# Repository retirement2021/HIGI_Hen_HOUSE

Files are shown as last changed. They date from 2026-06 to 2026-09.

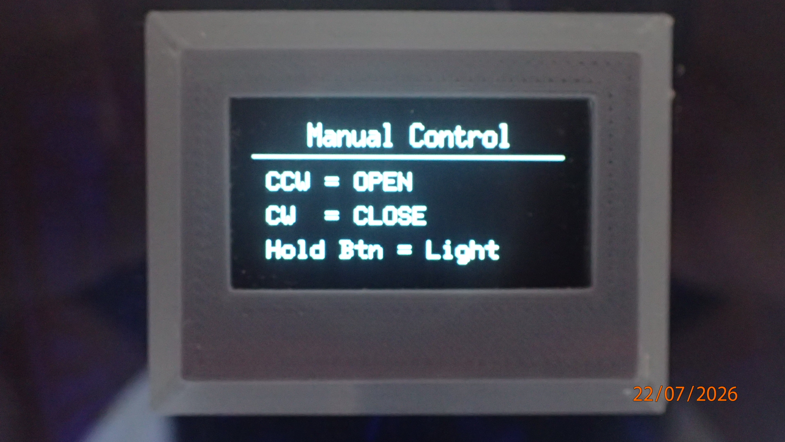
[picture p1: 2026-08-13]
Photos/Manual Page.png

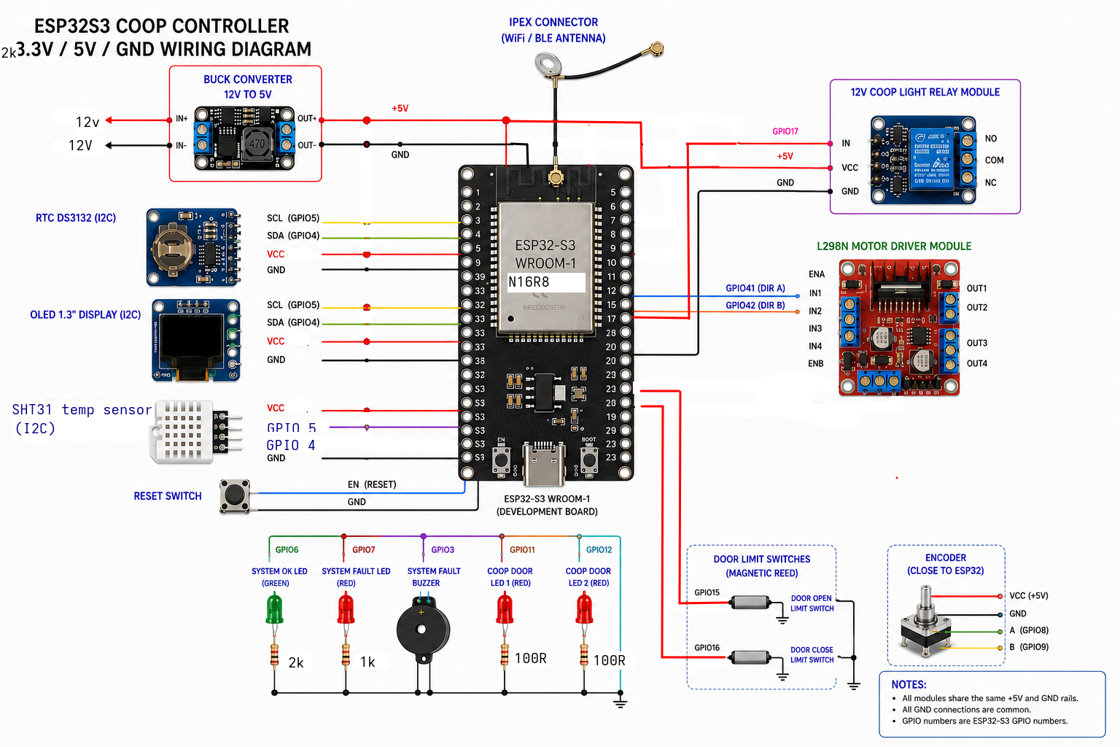
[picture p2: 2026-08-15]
Wiring/Logic Level Wiring Diagram.png

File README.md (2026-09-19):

# 🐔 Automated Hen House Controller

### ESP32-S3 based automatic chicken-coop door, lighting and environmental monitoring system

An automated hen-house control system built around an **ESP32-S3**. The system controls a **guillotine-style chicken door powered by a geared motor**, providing automatic opening and closing while incorporating multiple safety features to protect the hens and the mechanism.

The controller also provides environmental monitoring, automatic lighting, an OLED user interface, event logging, Wi-Fi time synchronisation and long-term temperature/humidity recording.

---

## ✨ Features

* 🐔 **Automatic guillotine-style door**
* ⚙️ Geared motor drive with OPEN/CLOSE control
* 🌅 Sunrise/sunset based scheduling
* 🕐 Separate GMT and BST schedules
* 🌡️ Inside and outside temperature/humidity monitoring
* ❄️ Cold-weather morning opening delay
* 💡 Automatic evening coop lighting
* 🔴 Progressive night/bedtime warning LEDs
* 🛡️ Door obstruction detection and recovery
* 🚪 Limit-switch monitoring and motor timeout protection
* 🔒 Fault detection and lockout system
* 🔔 Audible fault alarm
* 📊 14-day environmental history
* 📝 100-entry event log
* 🕰️ DS3231 RTC with NTP time synchronisation
* 📶 Wi-Fi monitoring and automatic reconnection
* 🖥️ 128×64 SH1106 1.3" OLED display
* 🎛️ Rotary encoder user interface
* 💾 Persistent settings and data storage
* 🐕 Watchdog protection for unattended operation

---

# 🏠 Door System

The hen house uses a **vertical guillotine-style door** driven by a **geared motor**.

The motor is controlled in both directions to raise and lower the door, with dedicated limit switches confirming the fully open and fully closed positions.

The door controller uses a state-machine architecture rather than simply running the motor for a predetermined time.

### Door safety features

* Separate OPEN and CLOSED limit switches
* Motor direction interlock
* 50 ms direction-change safety delay
* motor timeout
* Door position detection at startup
* Automatic homing if the door position is unknown
* Limit-switch conflict detection
* Closing obstruction detection
* Automatic reopening after an obstruction
* Times chicken-release period
* Maximum obstruction retries
* Fault and lockout states
* Manual fault reset

If the door encounters an obstruction while closing,  the door automatically reopens to allow the Chicken to clear the area before attempting to close again.

---

# 🌅 Automatic Door Operation

Door operation can be configured around **sunrise and sunset**, or fixed open times.

Separate settings are available for:

* **GMT / winter**
* **BST / summer**

The controller automatically detects UK daylight-saving time and selects the appropriate schedule.

The fixed opening times can be disabled to allow the door to operate relative to sunrise instead.

---

# ❄️ Cold Weather Protection

An external waterproof **SHT30 temperature/humidity sensor** monitors the outside temperature.

If the outside temperature is below the configured threshold when the morning door opening is due, the system can delay opening.

If the temperature rises above the threshold during the delay, the door can open immediately.

A manual override is also available to allow the door to open regardless of the outside temperature.

A dedicated blue LED indicates when the outside temperature is below the configured cold threshold.

---

# 🌡️ Environmental Monitoring

Two Sensirion SHT3x-family sensors are used.

| Sensor | Location | I²C Address |
| --- | --- | ---: |
| SHT31  | Inside hen house | `0x45` |
| SHT30  | Outside | `0x44` |

The sensors monitor:

* Temperature
* Relative humidity
* Daily minimum temperature
* Daily maximum temperature
* Daily minimum humidity
* Daily maximum humidity
* Time of recorded extremes

Approximately **14 days of environmental history** is retained for both inside and outside measurements.

Data is stored using the ESP32 `Preferences` system so that it survives power loss.

---

# 💡 Lighting & Night System

The controller operates the hen-house light automatically around sunset.

The evening chicken homing system uses two LEDs to provide a visual indication as closing time approaches.

The homing sequence progressively increases the flashing rate as the door-closing time gets closer.

Once the door is confirmed fully closed, the LEDs enter **night mode** and alternate throughout the night.

The coop light can also be operated manually using the rotary encoder.

---

# 🖥️ User Interface

A **128×64 SH1106 OLED** provides information and limited control without requiring a computer or web interface.

The rotary encoder is used for navigation and manual control.

### Display pages

1. **Main Status**
2. **Today's Schedule**
3. **Inside Environment**
4. **Outside Environment**
5. **Manual Controls**
6. **Event History**
7. **Wi-Fi Status**
8. **System Time**

The display normally refreshes only when required to reduce unnecessary I²C activity. 

The OLED also enters power-save mode after a period of inactivity.

---

# 📝 Event Logging

The controller maintains a circular **100-entry event history** with time stamps.

Events include:

* Automatic door opening
* Automatic door closing
* Manual door operation
* Light operation
* Cold-weather delays
* Obstruction detection
* Door timeouts
* Homing operations
* Faults
* Wi-Fi events
* Sensor faults
* System resets

This provides a useful history when diagnosing the system or checking its operation.

---

# 🕰️ Timekeeping

The system uses two time sources:

### Primary

**NTP via Wi-Fi**

### Backup

**DS3231 RTC**

When Wi-Fi is available, the ESP32 synchronises its clock using NTP and updates the DS3231.

If Wi-Fi is unavailable, the RTC provides a backup time source so that automatic door operation can continue.

UK GMT/BST daylight-saving rules are handled automatically.

---

# 📶 Wi-Fi

Wi-Fi is primarily used for:

* NTP time synchronisation
* Connection monitoring
* Automatic reconnection
* Signal-strength monitoring
* IP-address display

The controller is designed so that normal hen-house automation does not depend on a permanent Wi-Fi connection.

---

# 🔌 Hardware

### Controller

**ESP32-S3 WROOM-1 / N16R8**

### Display

**1.3" 128×64 SH1106 OLED**

### Sensors

* Sensirion SHT31 – inside
* Sensirion SHT30 – outside (waterproof)

### RTC

**DS3231**

### Door

* Guillotine-style vertical door
* Geared DC motor
* Motor driver
* OPEN limit switch (reed switch)
* CLOSED limit switch (reed switch)

### User control

* KY-040 rotary encoder

---

# 📌 ESP32-S3 Pinout

| Function | GPIO |
| --- | -----: |
| I²C SDA |  **8** |
| I²C SCL |  **9** |
| Rotary Encoder CLK |  **4** |
| Rotary Encoder DT |  **5** |
| Encoder Button | **18** |
| Door Motor OPEN | **41** |
| Door Motor CLOSE | **42** |
| Door OPEN Limit | **15** |
| Door CLOSED Limit | **16** |
| Coop Light | **17** |
| Green Status LED |  **6** |
| Red Fault LED |  **7** |
| Night LED 1 | **11** |
| Night LED 2 | **12** |
| Cold Temperature LED | **13** |

All I²C devices share the same bus at **100 kHz**.

---

# 🛡️ Safety Philosophy

Because the system controls a physical door containing live animals, safety is a major part of the design.

The controller does not rely on a single timing mechanism to determine door position.

Instead it combines:

**Limit switches + motor timeout + state machine + obstruction detection + recovery + fault lockout**

The system also performs a door-position check during startup and will attempt to home the door if its position cannot be established.

---

# 💾 Firmware

**Current Version: V2.14**

The project has evolved through several revisions, including the transition from a DHT22 sensor to the SHT3x family and the addition of the external temperature sensor and cold-weather door protection. Additional refinements and tweaks to get as close to a plug and play install as i can.

### V2.04 highlights

* SHT31 inside sensor
* SHT30 outside sensor
* Dual I²C sensor support
* Outside environmental monitoring
* Cold-weather opening delay
* Temperature-based delay cancellation
* Persistent environmental history
* Improved event logging
* Environmental log maintenance functions

---

# 🔧 Development Notes

The OLED, DS3231 and both temperature sensors share the same I²C bus.

Reliable physical wiring is important for I²C operation. In testing, intermittent display problems were ultimately traced to unreliable **fly-lead connections between the ESP32-S3 and OLED**. Replacing the leads and soldering the connections resolved the problem.

This is worth considering when reproducing the hardware, particularly where longer or flexible wiring is used.

---

# ⚠️ Disclaimer

This is a personal DIY automation project.

A motorised animal door should be thoroughly tested under real operating conditions before being left unattended. Particular attention should be given to the mechanical door design, limit switches, obstruction detection, motor drive system and emergency/fault conditions.

---

## 📷 Project

**Hen House Automation — ESP32-S3**

*Automatic door • Environmental monitoring • Lighting • Safety • Data logging*

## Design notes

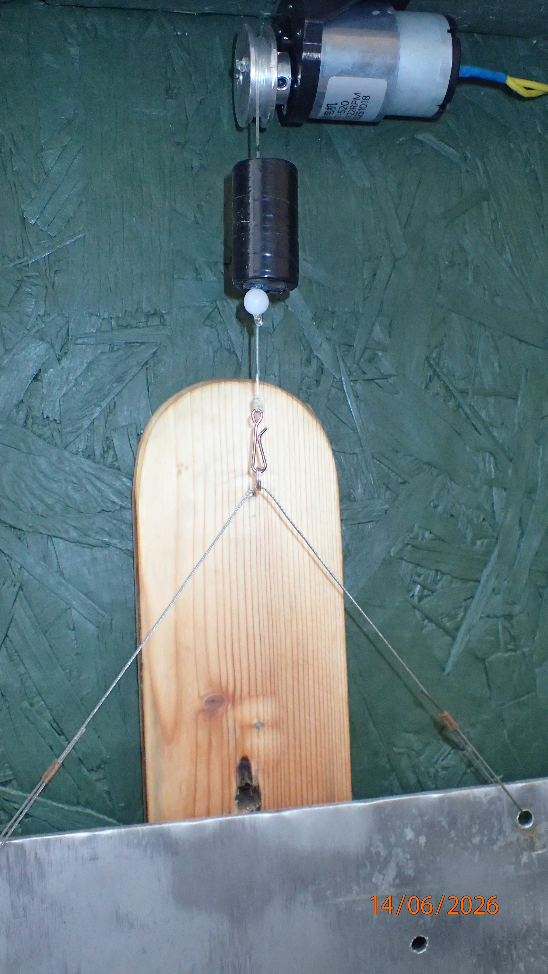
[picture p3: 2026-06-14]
Photos/150g weight to take up slack.JPG

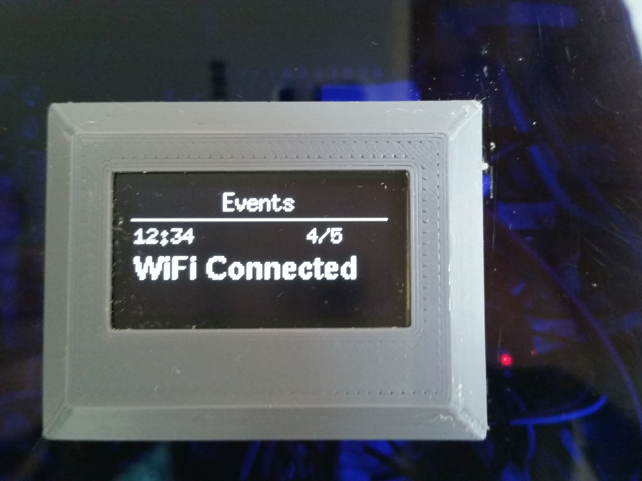
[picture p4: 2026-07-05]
Photos/Events page.jpg

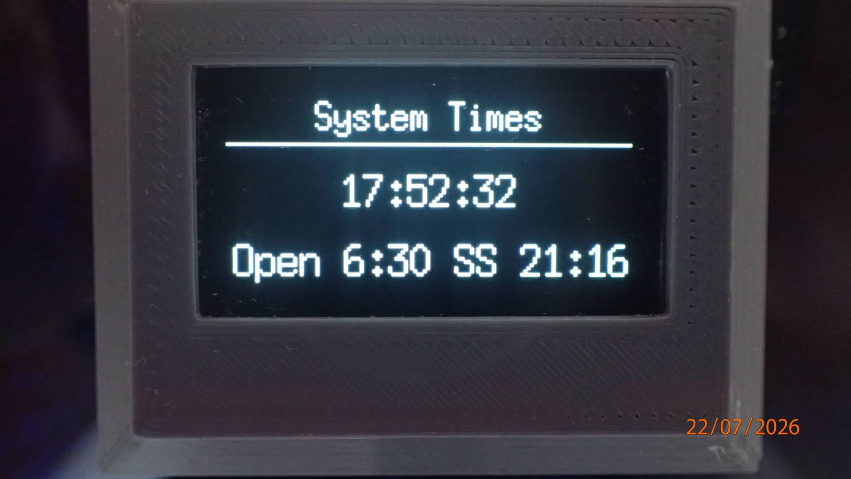
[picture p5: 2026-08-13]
Photos/System Times.png

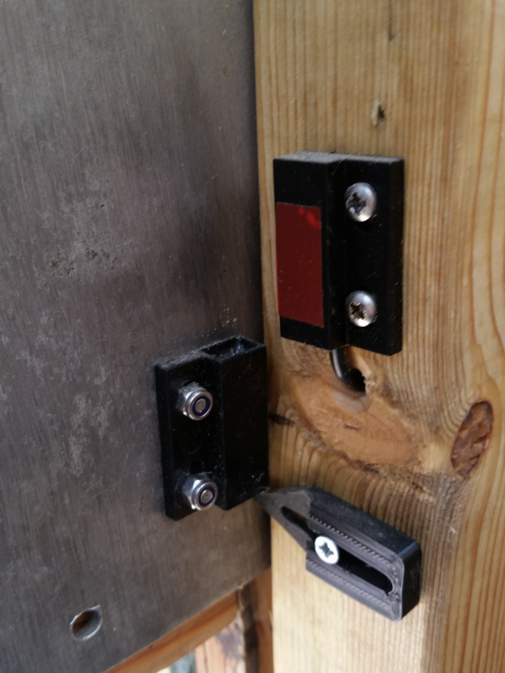
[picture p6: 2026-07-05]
Photos/Upper-limit switch.jpg

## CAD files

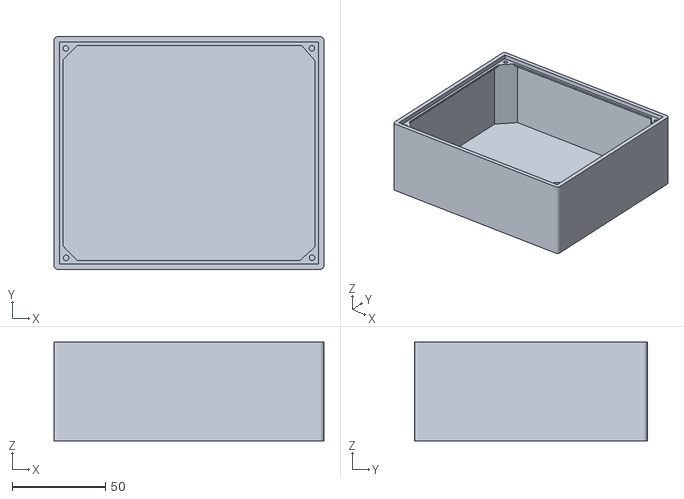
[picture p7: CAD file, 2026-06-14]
3D Printed parts/Control box/Hen House Control Box.stl
145.0 x 125.0 x 53.0

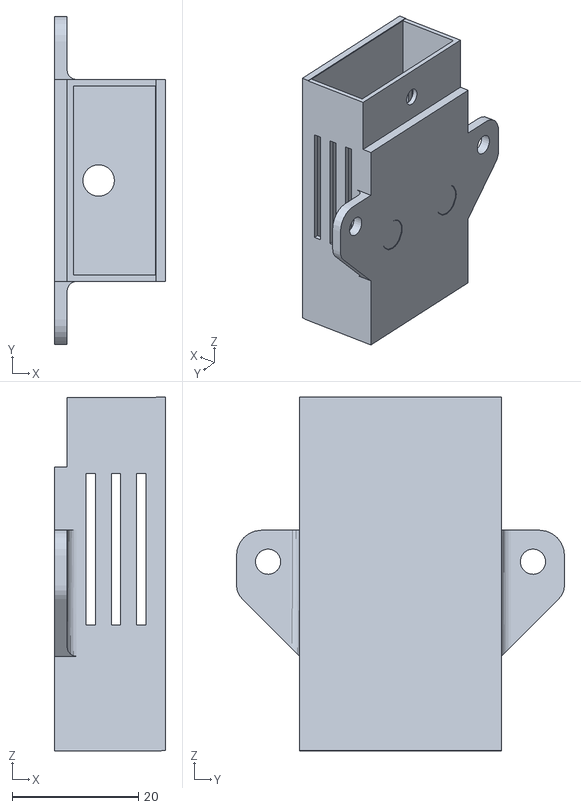
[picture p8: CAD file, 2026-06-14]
3D Printed parts/DHT temp sensor box/DHT box .stl
17.6 x 52.0 x 56.1

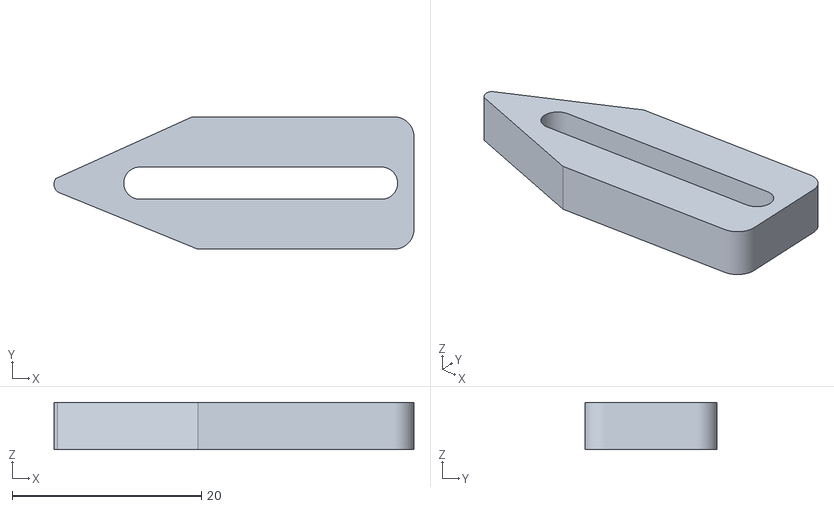
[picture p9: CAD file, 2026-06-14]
3D Printed parts/Door slider fine adjust/door slider points, 2 per side.stl
38.1 x 14.0 x 5.00

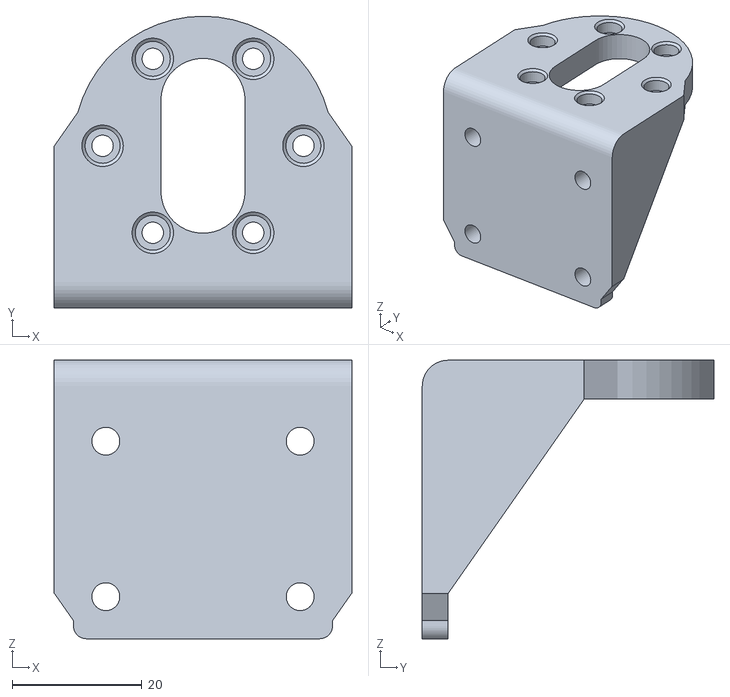
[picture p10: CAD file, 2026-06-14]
3D Printed parts/JGB37-520 Motor Mount.stl
46.0 x 45.0 x 43.0

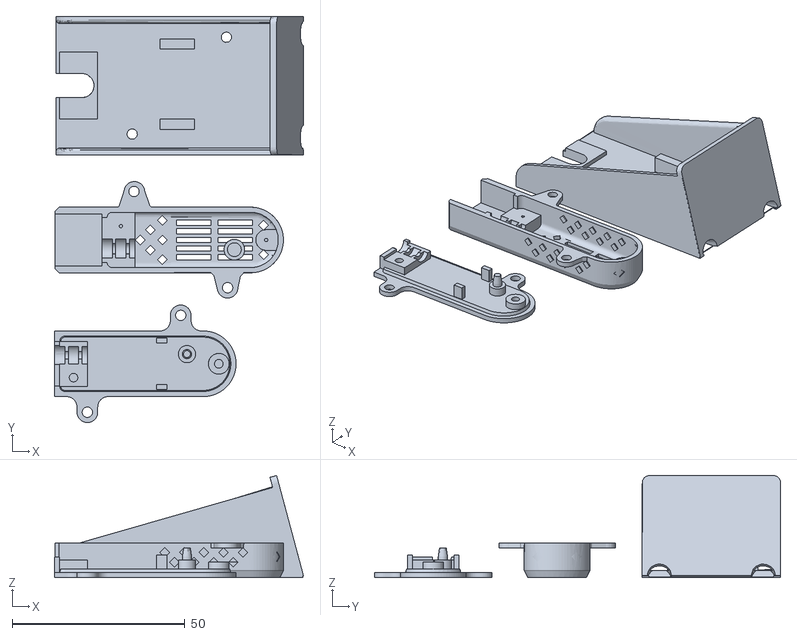
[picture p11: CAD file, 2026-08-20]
3D Printed parts/SHT Temperature sensor Enclosures/SHT Coop Sensor Mount.stl
72.0 x 117.4 x 29.5

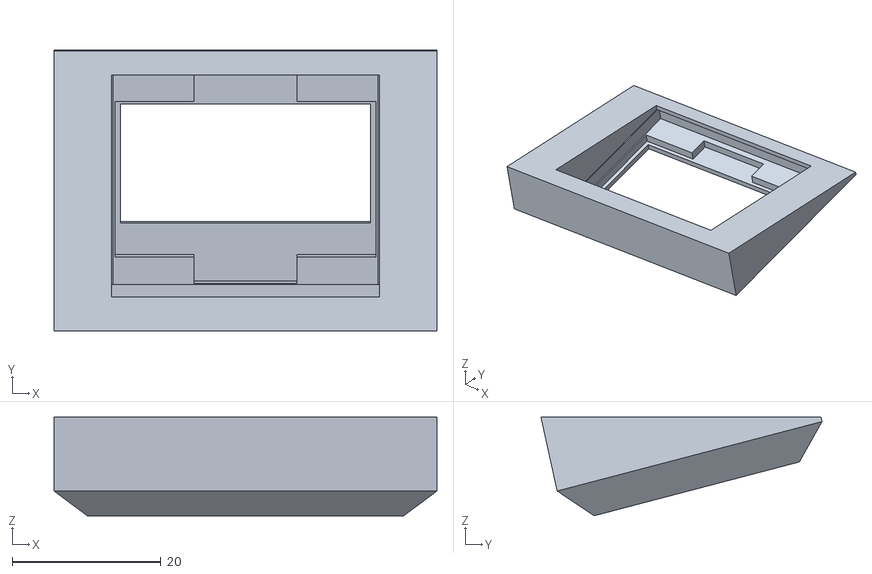
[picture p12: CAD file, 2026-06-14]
3D Printed parts/Control box/1.3 angled Bezel MKII.stl
51.5 x 37.8 x 13.2

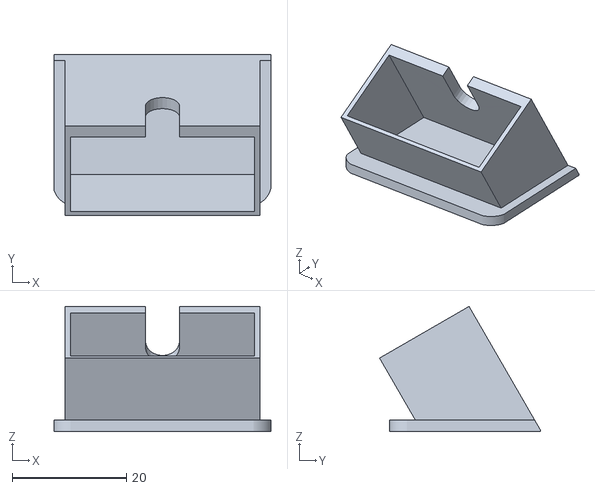
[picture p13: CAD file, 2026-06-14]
3D Printed parts/DHT temp sensor box/DHT lid .stl
38.0 x 28.2 x 21.9

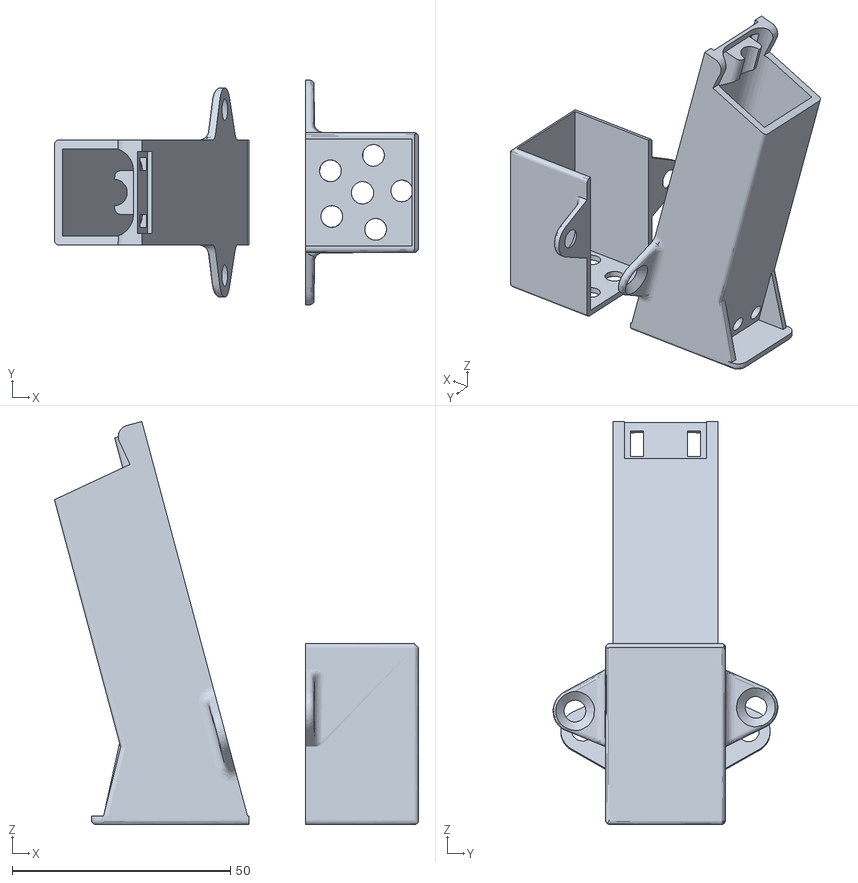
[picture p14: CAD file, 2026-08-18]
3D Printed parts/SHT Temperature sensor Enclosures/ SHT Outide Sensor Enclosure .stl
83.5 x 51.5 x 92.3

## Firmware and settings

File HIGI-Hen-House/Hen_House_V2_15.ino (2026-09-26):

// System: ESP32S3 N16R8 board.
// Arduino IDE: ESP32S3 Dev Module

// Author HIGI-Styx
// Febuary-September 2026


//  https://github.com/retirement2021/HIGI_Hen_HOUSE for Robust versions, wiring diagrams, photos, 3D printing files, and a complete parts list.

// 2.15
// Long term 

// V2.14
// NVS logging problems reducing the amount of data and the number of days that can be comfortably stored

// V2.13
// Remove the current time and 1 second refresh on System Time page and replace with Cold threshhold temp.
// Change the title of that page to Cold & Daytime.

// V2.12
// Amalgamated inside and outside environmental pages into one, for convenient viewing.

// V2.10
// removed the clear persistent environment logs on the next upload as it was the culprit to NVS logging fails.

// 2.04
// Rewrote the Environment Outside pages inline with the Environment Inside pages for consistency.
// Futher refinement to the cold delay logic to poll the external temperature sensor immediately before the door opens, then reset the polling timer.

// V2.02
// Refined cold delay logic to evaluate temperature immediately prior to door opening, logging a "Cold Delay" event when triggered.
// Added a option to clear internal and external persistent environment logs on the next upload.

// V2.01
// Added support for an SHT30 outdoor temperature probe at address 0x44, complete with dedicated display pages and logging.
// Replaced the Adafruit_SHT31 library with SensirionI2CSHT3x to support dual SHT3x sensors on separate I2C addresses.
// Updated the I2C address for the SHT31 coop sensor to 0x45.
// Implemented a cold weather morning door delay when outdoor temperatures fall below a configurable threshold.
// Added a 24/7 Cold (blue) LED indicator that illuminates when ambient temperature drops below the configured setpoint.

// V2.0
// Changed from a DHT22 coop temp sensor to a SHT31 sensor.


//------------------------

// This project has evolved to enable long-term autonomous operation with minimal user intervention.

// An automated coop management system that synchronizes door operation and lighting with natural sunrise/sunset times,
// Continuously tracks environmental metrics, and integrates robust safety protocols to protect the flock and hardware.

// Tailored for UK time zones and DST shifts.
// Only requires a minimal Wi-Fi signal to perform NTP time synchronization.
// All customizable settings are centralized in one block under two headers: *USER SETTINGS* and *USER MAGIC NUMBERS*.
// Integrated motor timeout protection to prevent motor burnout during mechanical door failures.
// Obstruction Protection: Smart door-reversal logic to release a trapped chicken during closure.
// Coop door and light operations sync with local sunrise/sunset times and feature fully customizable settings to accommodate your flock's routine.
// Rooster Crow Control: Optional fixed-time door opening schedule to delay early morning crowing.
// System operation uses a rotary encoder. Perform a long press (≥5 seconds) to reset system faults.



//======================================================
// LIBRARYS
//======================================================
#include <WiFi.h>
#include <time.h>
#include <math.h>
#include <Wire.h>
#include <RTClib.h>
#include "secrets.h"
#include <U8g2lib.h>
#include <Preferences.h>
#include <esp_task_wdt.h>
#include <SensirionI2cSht3x.h>
#include <AiEsp32RotaryEncoder.h>

// ======================================================
// TIME VALUES
// ======================================================
// Converts milliseconds into readable; seconds, minutes and hours.

const unsigned long SECOND = 1000UL;
const unsigned long MINUTE = 60000UL;
const unsigned long HOUR = 3600000UL;

// ******************************************************
// ********USER SETTINGS*********
// ******************************************************

//--------------------------------------
//  SYSTEM
//--------------------------------------
// Displayed firmware version
const char systemVersion[] = "V2.15";

//"""""""""""
// WINTER
//"""""""""""

//~~~~~~~~~~~~~~~~~~~~~~~~~~~~~~~~~~~~~~
// DOOR OPENING OPTION (GMT only)
//~~~~~~~~~~~~~~~~~~~~~~~~~~~~~~~~~~~~~~

// GMT (Winter only):
//   Choose sunrise OR fixed opening time
// * false = Sunrise     (GMT Winter only)
//   true  = Fixed time  (GMT Winter only) ~Rooster Crow Control
bool useFixedOpenTimeGMT = true;

// Fixed opening time for GMT Winter (24-hour clock)
int fixedDoorOpenHourGMT = 8;     // GMT fixed open hour (24-hour)
int fixedDoorOpenMinuteGMT = 00;  // GMT fixed open minute

//-------------------------------------
//  DOOR GMT TIME. (winter)
//-------------------------------------
// Positive offset = AFTER  sunrise/sunset
// Negative offset = BEFORE sunrise/sunset.

//MORNING.
// * Active only when "DOOR OPENING OPTION" is set to "false". (GMT Winter only)
// Door opening offset from sunrise - GMT
int sunriseOpenOffsetGMT = +20;  // __ minutes after sunrise

//EVENING
// Door closing offset from sunset - GMT
int sunsetCloseOffsetGMT = +15;  // __ minutes after sunset

//--------------------------------------
//  LIGHT GMT TIME. (winter)
//--------------------------------------
// Positive offset = AFTER  sunrise/sunset
// Negative offset = BEFORE sunrise/sunset.

//LIGHT ON
// Coop light ON offset from sunset - GMT
int lightOnOffsetGMT = -13;  // __ minutes before sunset

//LIGHT OFF
// Coop light OFF offset from sunset - GMT
int lightOffMinutesGMT = +7;  // __ minutes after sunset

//-------------------------------------------------------
//  OUTSIDE SHT30 TEMPERATURE SENSOR + COLD-OPEN SETTINGS
//-------------------------------------------------------

bool enableOutsideSHT = true;  // Set to "false" if no outdoor temperature sensor is installed.

float outsideTempTriggerC = -2;        // Delays scheduled door opening when outside temp is under ___ °C (also triggers 24/7 Cold LED).
int doorOpenDelayIfColdMinutes = +35;  // Minutes to delay door opening time.

bool forceOpenDespiteCold = false;  // set true to ignore door cold-delay (persistent)


//""""""""""""
// SUMMER
//""""""""""""

//~~~~~~~~~~~~~~~~~~~~~~~~~~~~~~~~~~~~~~
// DOOR OPENING OPTION (BST only)
//~~~~~~~~~~~~~~~~~~~~~~~~~~~~~~~~~~~~~~

// BST (summer only):
//   Choose sunrise OR fixed opening time
// * false = Sunrise     (BST summer only)
//   true  = Fixed time  (BST summer only) ~Rooster Crow Control
bool useFixedOpenTime = true;

// Fixed opening time for BST summer (24-hour clock)
int fixedDoorOpenHour = 7;
int fixedDoorOpenMinute = 55;

//------------------------------------
//  DOOR BST TIME (summer)
//------------------------------------
// Positive offset = AFTER  sunrise/sunset
// Negative offset = BEFORE sunrise/sunset.

//  MORNING -
//  * Active only when "DOOR OPENING OPTION" is set to "false". (BST summer only)
//  Door opening offset from sunrise - BST
int sunriseOpenOffsetBST = +30;

//EVENING
// Door closing offset from sunset - BST
int sunsetCloseOffsetBST = +20;

//------------------------------------
//  LIGHT BST TIME (Summer)
//------------------------------------
// Positive offset = AFTER  sunrise/sunset
// Negative offset = BEFORE sunrise/sunset.

//LIGHT ON
// Coop light ON offset from sunset - BST
int lightOnOffsetBST = -7;

//LIGHT OFF
// Coop light OFF offset from sunset - BST
int lightOffMinutesBST = +13;

//--------------------------------------
// Coop Door LED indications
//--------------------------------------
// Visual Chicken Homing
// Progressive bedtime flash stages.

const unsigned long BEDTIME_STAGE0_DELAY_MINS = 0;  // Stage 0: Minutes after coop light comes ON. default 0
const unsigned long BEDTIME_STAGE1_MINS = 12;       // Stage 1: Minutes before door close. default 12
const unsigned long BEDTIME_STAGE2_MINS = 6;        // Stage 2: Minutes before door close. default 6
const unsigned long BEDTIME_STAGE3_MINS = 1;        // stage 3: Minutes before door close. default 1

// Progressive bedtime flash speed. (1000  milli-seconds = 1 second)

const unsigned long STAGE0_FLASH_MS = 1000;  // Stage 0: Slower flash. default 1000. Bug Note 1: Must end in *00 to avoid a known software issue.
const unsigned long STAGE1_FLASH_MS = 700;   // Stage 1: Medium flash. default 700.  Bug Note 1.
const unsigned long STAGE2_FLASH_MS = 400;   // Stage 2: Faster flash. default 400.  Bug Note 1.
const unsigned long STAGE3_FLASH_MS = 200;   // Stage 3: Quick  flash. default 200.  Bug note 1.


// Visual Door Closed.
// Night Alternating Flash will only start once the lower limit switch detects that the door is fully closed.

const unsigned long NIGHT_FLASH_MS = 1200;  //  Flashes continuously overnight until the morning door opening sequence triggers. Default 1200. Bug Note 1.

//======================================
// Manual coop light auto OFF timer.
//--------------------------------------
unsigned long manualLightTimeout = 10 * MINUTE;  // default 10 minutes


//******************************************************
//*******USER MAGIC NUMBERS*******
//******************************************************

//--------------------------------------
//*** MOTOR IMPORTANT SETUP ***
//-------------------------------------------------------------------------------------------------------------------------------------------------------------------------------

// Normal door open/close timing
#define MOTOR_TIMEOUT (15 * SECOND)  // Motor timeout protection, protects the motor from burn out if the door fails in any way.
//                                      Adjust for how long the door motor runs between the lower & upper door limit switches (from fully closed to fully open position) \
//                                      Check Event page, eg "DOOR OPEN 14.1s", add 1-2 seconds. Keep this tight.

// Automatic door obstruction timing. Chicken release logic
#define MOTOR_TIMEOUT_RECOVERY (18 * SECOND)  // Only triggered when a door obstruction is detected (chicken blocking the door way).Time difference between MOTOR_TIMEOUT and MOTOR_TIMEOUT_RECOVERY. eg additional 3 seconds. \
//                                               Allows for the "MOTOR_TIMEOUT" time to finish (full 15 seconds) plus a few seconds for the extra cord to unwind and rewind, eliminating a MOTOR_TIMEOUT fault. \
//                                               Once triggered, check Event page, find the sequence, eg "Close Obstruction", "Auto Safety", "Door Open 15.9s", add 2-4 seconds. \                                              
//---------------------------------------------------------------------------------------------------------------------------------------------------------------------------------


// Door Obstruction Pause
#define SAFETY_WAIT_AFTER_REOPEN_MS (180 * SECOND)  // When the system registers a door obstruction, it re-opens the door (to release the hen)
//                                                   This function holds the door open for a pause of __ seconds before a retry of the door obstruction CLOSE.
//                                                   Allowing the released chicken time to re-enter the coop.

// Door Obstruction Retries
const int MAX_OBSTRUCTION_RETRIES = 3;  // Number of attemps to fully close the door before a fault condition occures.

//-------------------------------------

// SHT31 Inside temperature/humidity Sensor
#define MAX_CONSECUTIVE_SHT_FAILURES 10        // Log fault after 10 consecutive failures
#define SHT_FIRST_READ_DELAY_MS (60 * SECOND)  // Delay before first reading ( __ seconds for sensor settling) Default 60 seconds
#define SHT_READ_INTERVAL_MS (13 * MINUTE)     // Subsequent reading interval every __ minutes. (reads in 24hrs: 9-minutes=160, 13-minutes=110, 17-minutes=85)

// SHT30 Outside temp/humidity sensor. (Offset from the SHT31's schedule to help prevent I2C bus congestion)
#define MAX_CONSECUTIVE_SHT_OUT_FAILURES 10            // Log fault after 10 consecutive failures
#define OUTSIDE_SHT_FIRST_READ_DELAY_MS (75 * SECOND)  // Delay before first reading ( __ seconds for sensor settling) Default 75 seconds
#define OUTSIDE_SHT_READ_INTERVAL_MS (9 * MINUTE)      // Subsequent reading interval every __ minutes. (reads in 24hrs: 9-minutes=160, 13-minutes=110, 17-minutes=85)

// SHT3x temperature sensor addresses
const uint8_t INSIDE_SHT_ADDRESS = 0x45;   // SHT31 (Link VIN to address pin for address 0x45)
const uint8_t OUTSIDE_SHT_ADDRESS = 0x44;  // SHT30 probe style,fixed address

// Evironment persistent Log Entries          // Bug Note 2. Display pages erratic if too many days are being logged
const int ENVIRONMENT_LOG_DAYS = 7;           // Inside env log.  Bug Note 2. Safe 7-14 days,  
const int ENVIRONMENT_LOG_DAYS_OUTSIDE = 14;  // Outside env log. Bug Note 2. 

// Events
#define MAX_EVENTS 100  // Number of events stored. default 100, Max 200

// WiFi
#define WIFI_RETRY_INTERVAL (90 * SECOND)  // If WiFi fails, retry every __ until connected. Default 90 seconds
#define MAX_WIFI_RETRIES 20                // Stop WiFi retry after this many attempts

// Rotary Encoder
#define ENCODER_DETENTS 3  // Detent threshold for manual door movement (prevents accidental triggers). Default 3

// BUZZER
unsigned long buzzerRepeatInterval = (15 * SECOND);  // Fault buzzer repeat interval. Default 15 seconds

// Display
unsigned long oledTimeout = (1 * MINUTE);  // Display sleeps after no activity. Default 1 minute

// Display Pages
// Change the order of the display pages

enum DisplayPage {

  PAGE_MAIN,         // Basic info
  PAGE_SCHEDULE,     // Today's door & light times. info only
  PAGE_MANUAL,       // Manual door open/close, light on/off. Interactive
  PAGE_ENVIRONMENT,  // Coop temp & humidity. Scroll info
  PAGE_EVENTS,       // Date stamped events. Scroll info
  PAGE_SYSTEM_TIME,  // Cold delay trigger temp, SunRise or fixed door open and SunSet time. Info only.
  PAGE_SYSTEM_WIFI   // IP and signal strength. Info only.
};

// Display Pages
#define NUM_DISPLAY_PAGES 7  // number of display pages.

// Always first display page
DisplayPage currentPage = PAGE_MAIN;

// Event Scroll Sensitivity
#define EVENT_SCROLL_TIMEOUT_MS (10 * SECOND)  // Exit event view after 10 sec inactivity

// Watchdog
#define WATCHDOG_TIMEOUT_MS (35 * SECOND)  // Watchdog timeout

// Safety Timeout
#define SAFETY_TIMEOUT (2 * MINUTE)  // adjust for overall fail safe


// ******************************************************
// ****END OF USER SETTINGS****
// ******************************************************

// ======================================================
// GPIO & connections specific to the ESP32 S3 board
// ======================================================

#define MOTOR_OPEN_PIN 41   // Motor OPEN door. Via a L298N or TB6612FNG controller
#define MOTOR_CLOSE_PIN 42  // Motor CLOSE door. Via a L298N or TB6612FNG controller

#define LIMIT_OPEN_PIN 15   // Door Limit Switch top, Reed switch, Normally open contacts. Connect to GND. (magnet to close circuit)
#define LIMIT_CLOSE_PIN 16  // Door Limit Switch bottom, Reed switch, Normally open contacts. Connect to GND. (magnet to close circuit)

#define LIGHT_PIN 17  // Auto Coop Light. To control a logic level relay board module. 3.3v or 5v coil

#define BUZZER_PIN 3  // 3V Active Buzzer for alert fault. Connect to GND

#define STATUS_LED_PIN 6  // 3mm GREEN LED connect to GND. System healthy. 2k+ resistor. High resistor to keep LED dim
#define FAULT_LED_PIN 7   // 3mm RED LED connect to GND. Fault warning. 1k resistor.

#define NIGHT_LED1_PIN 11  // 5mm RED LED connect to GND. Installed above the Coop door for chicken homing & visual referance. 100-330R resistor. (forward voltage 1.6v-2.1v)
#define NIGHT_LED2_PIN 12  // 5mm RED LED connect to GND. Installed above the Coop door for chicken homing & visual referance. 100-330R resistor.

#define COLD_LED_PIN 13  // 5mm Blue LED connect to GND. (outside cold indicator) Installed above the Coop door visual referance. 5R-10R resistor.(forward voltage 3v-3.6v)

// Rotary Encoder
#define ENCODER_CLK_PIN 4  // KY-040
#define ENCODER_DT_PIN 5   // KY-040
#define ENCODER_SW_PIN 18  // KY-040

// Temp & Humidity
SensirionI2cSht3x sht3xInside;   // Inside SHT31 - 0x45
SensirionI2cSht3x sht3xOutside;  // Outside SHT30 - 0x44

// =======================================================
// ADDITIONAL GPI0 PIN INFO
// =======================================================
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
void loop() {

  esp_task_wdt_reset();

  updateEnvironment();

  rolloverEnvironmentLog();

  updateOutsideEnvironment();

  handleSwitch();

  handleEventScroll();

  updateDoor();

  updateSafetyCycle();

  motorSafetyCheck();

  updateBuzzerPattern();

  updateStatusLEDs();

  updateNightLeds();

  connectWiFi();

  refreshDisplayIfNeeded();

  // ==========================================
  // MANUAL LIGHT AUTO OFF
  // ==========================================

  if (manualLightOverride && manualLightOffTime > 0 && millis() >= manualLightOffTime) {

    manualLightOverride = false;

    manualLightOffTime = 0;

    lightOn = false;

    digitalWrite(LIGHT_PIN, LOW);

    setEvent("Light Timeout");
  }

  if (!oledSleeping && millis() - lastOledActivity > oledTimeout) {

    u8g2.clearBuffer();
    u8g2.sendBuffer();

    u8g2.setPowerSave(1);

    oledSleeping = true;
  }

  if (millis() - lastCheck > 1 * MINUTE) {

    lastCheck = millis();

    struct tm timeinfo;
    if (!getTime(timeinfo)) {
      setEvent("Time failed");
      return;
    }

    updateSunTimes(timeinfo);

    // Save environment log to persistent storage daily (inside + outside + today's values)
    static int lastSavedDay = -1;
    if (timeinfo.tm_mday != lastSavedDay) {
      lastSavedDay = timeinfo.tm_mday;
      persistEnvironmentHistoriesToPrefs();
      Serial.println("Daily history backup saved (in + out)");
    }

    int nowMinutes = (timeinfo.tm_hour * 60) + timeinfo.tm_min;

    autoState = computeAutoState(nowMinutes);

    //===========================================
    // Door Auto State
    //===========================================

    static AutoState lastAutoState = AUTO_IDLE;

    if (autoState != lastAutoState) {

      switch (autoState) {

        case AUTO_IDLE:
          setEvent("Auto_Idle");
          break;

        case AUTO_ALLOWED:
          setEvent("Auto_Allowed");
          break;

        case AUTO_LOCKED_MANUAL:
          setEvent("Auto_Locked");
          break;

        case AUTO_SAFETY_RECOVERY:
          setEvent("Auto_Safety");
          break;
      }

      lastAutoState = autoState;
    }

    updateLight(nowMinutes);

    if (autoState == AUTO_ALLOWED) {

      // ---------- AUTO OPEN: one-time morning check at scheduled openTime ----------
      if (doorState == DOOR_CLOSED) {

        // We already have timeinfo above
        int today = timeinfo.tm_yday;

        // Perform the one-time morning check only once per day
        if (coldDelayCheckedDay != today) {

          // Only evaluate when we've reached (or passed) the scheduled open time
          if (nowMinutes >= openTime) {

            // Mark we've performed the morning check so we won't do it again today
            coldDelayCheckedDay = today;

            // Decide whether to apply the cold delay (only now, once per day)
            // First: try to refresh the outside reading up to 3 attempts and reset its read timer
            if (enableOutsideSHT && !forceOpenDespiteCold) {
              pollOutsideSensorNow(3);
            }

            bool applyDelay = false;

            if (enableOutsideSHT && !forceOpenDespiteCold && !isnan(currentTempOutside)) {
              if (currentTempOutside < outsideTempTriggerC) applyDelay = true;
            }

            if (applyDelay) {
              // Set the delayed open minute and record the day
              delayedOpenTime = openTime + doorOpenDelayIfColdMinutes;
              if (delayedOpenTime >= 24 * 60) delayedOpenTime -= 24 * 60;
              coldDelayDay = today;

              // Log a single "Cold Delay" event now that the morning opening was postponed
              setEvent("Cold Delay");
              coldDelayLogged = true;
            } else {
              // Temperature is OK (or sensor missing) — open immediately
              setEvent("Auto Open");
              startOpening();
            }
          }
        }

        // If we've already performed today's check and a delayedOpenTime exists, handle it
        else {
          if (delayedOpenTime >= 0) {

            // Allow cancellation of the previously-applied delay if temp warms before delayed time
            if (enableOutsideSHT && !forceOpenDespiteCold && !isnan(currentTempOutside) && currentTempOutside >= outsideTempTriggerC) {
              // Cancel the delay silently (no event)
              delayedOpenTime = -1;
              coldDelayDay = -1;
              coldDelayLogged = false;

              // If we're within the operating window, open immediately
              if (nowMinutes >= openTime && nowMinutes < closeTime) {
                setEvent("Auto Open");
                startOpening();
              }
            }
            // If not cancelled, open when delayed time is reached
            else if (nowMinutes >= delayedOpenTime && nowMinutes < closeTime) {
              delayedOpenTime = -1;
              coldDelayDay = -1;
              coldDelayLogged = false;
              setEvent("Auto Open");
              startOpening();
            }
          }
        }
      }

      // ---------- AUTO CLOSE (unchanged) ----------
      if (doorState != DOOR_CLOSED && nowMinutes >= closeTime) {
        setEvent("Auto Close");
        startClosing();
      }
    }
  }
}

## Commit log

2026-06-11 Update parts list with DHT22 sensor
    Added DHT22 sensor to the temperature and humidity section.
2026-06-14 Rename Magnet on the door, rees switch and slider point.JPG to Magnet on the door, reed switch and slider point.JPG
2026-06-14 Update temperature/humidity monitoring description
2026-06-15 Update • My chosen design and materials
2026-07-05 Fix formatting in README for temperature storage
    Corrected formatting of '30 day' in the features list.
2026-07-12 Add LM2596 buck converter to hardware list
2026-08-14 Add files via upload
    Added an extra display page showing today’s actual door opening and closing times, along with the light on/off times, with all times adjusted to account for the configured offsets.
2026-08-15 Add files via upload
    Re-wrote Environment update block to reduce spurious temperatures being logged
2026-08-15 Add files via upload
    Replace temperature sensor DHT22 with newer SHT31 sensor
    [Hen_House_V2_0.ino]
2026-08-15 Revise README for sensor updates and version changes
    Updated sensor information in the README file to reflect the retirement of the DHT22 and the upcoming development of Version 2 with the SHT31 sensor.
2026-08-15 Final version using DHT22 temperature sensor
    Re-wrote update-Environment to reduce spurious temperatures being logged.
2026-08-15 Replace old DHT22 with a newer SHT31 temperature sensor
    Upgraded the the temperature humidity sensor from DHT22 to a newer more robust sensor SHT31. All DHT coding replaced and all functions retained
    [Hen_House_V2_0.ino]
2026-08-15 Update README with version information for sensors
2026-08-15 Add SHT31 Temperature sensor to parts list
2026-08-16 Replaced old DHT22 with newer SHT31 sensor
    [Hen_House_V2_0.ino]
2026-08-17 SHT 3x sun shield
    [SHT3x sun shield.stl]
2026-08-18 Update HIGI Hen House parts list with new sensors
    Added SHT40 Weather resistant Temperature Sensor to the parts list.
2026-08-18 External Sensor Enclosure
    [External Temp Sensor Enclosure SHT (1).stl]
2026-08-18 External Sensor Enclosure
    Skinny enclosure for a waterproof SHT sensor
    [External Temp Sensor Enclosure SHT .stl]
2026-08-18 External SHT Sensor Enclosure
    Skinny Sensor Enclosure for a prewired SHT waterproof Sensor
    [External Temp Sensor Enclosure SHT.stl]
2026-08-20 SHT Coop sensor mount
    [SHT coop sensor mount.stl]
2026-08-20 SHTxx Sensor Enclosures
    [SHT Outide Sensor Enclosure .stl, SHT Coop Sensor Mount.stl]
2026-08-21 Revise README for sensor updates and new features
    Updated version information for SHT3x and SHT4x sensors, added details about new features and libraries.
2026-08-25 Revise version details for temperature sensor updates
    Updated version information for the temperature sensor in the README.
2026-08-28 Add files via upload
    added an external temp sensor and cold door opening delay.
2026-08-29 Revise HIGI Hen House parts list
    Updated the parts list for the HIGI Hen House, correcting sensor names and adding missing components.
2026-10-28 Update press time condition for page change
    debounce the encoder press to prevent pages being skipped
2026-10-29 Fix formatting of pin assignments in README.md
2026-11-05 Update DC to DC buck converter link
    Updated the link for the DC to DC step down buck converter in the parts list.
2026-11-06 Changing card colours
    Most of the cards change colour, title card changes with to sunrise and sunset times, Temp and humidity change with the inside and out side temps. coop light boarder changes according to light on/off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
